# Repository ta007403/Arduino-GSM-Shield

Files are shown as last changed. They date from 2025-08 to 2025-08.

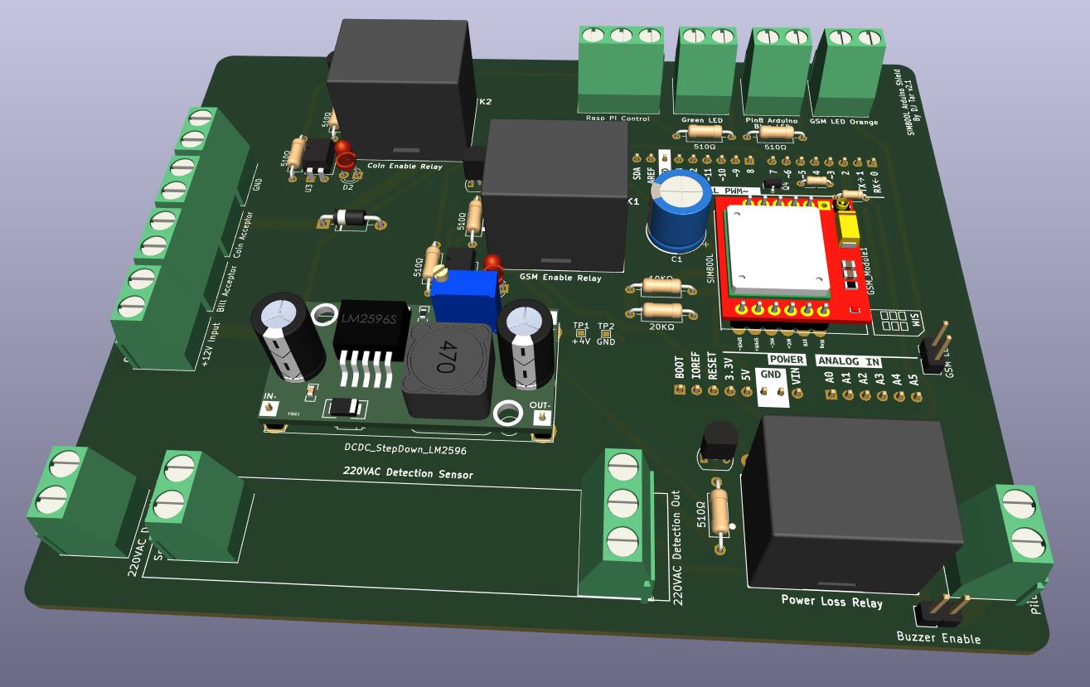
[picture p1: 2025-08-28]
plots/Smart Coin PCB Version 2.1.JPG

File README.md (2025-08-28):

Smart Coin Machine PCB (v2.1)

Smart Coin PCB Version 2 1

This project is a custom PCB for smart coin and bill acceptor machines, designed to simplify wiring, assembly, and integration with GSM modules, Arduino, and Raspberry Pi.

✨ Features

Plug & Play Wiring

Just connect +12V DC input via screw terminals.

Direct connections for coin acceptor, bill acceptor, buzzer, and status LEDs.

GSM Module Support

Compatible with SIM800L and SIM800C.

On-board relay to enable/disable GSM module.

Reset GSM via dedicated relay (Arduino Pin 7).

Built-in DC-DC step-down regulator (LM2596S) provides stable +4V supply for GSM.

Relays & Control

Coin Enable Relay → controlled by Raspberry Pi (Pin 17).

GSM Enable Relay → power cycle or disable GSM when needed.

Power Loss Relay → detect and respond to AC mains failures.

Indicators & Status LEDs

Arduino Pin 8 → Blue LED status output.

Raspberry Pi Pin 27 → Green LED status output.

GSM status LED indicators (Orange).

220VAC Detection

Input and output connectors for 220VAC detection sensor.

Useful for monitoring AC mains availability.

----------------------------------------------------------------------------------------

📐 Hardware Overview

Main components visible on the PCB:

LM2596S DC-DC Buck Converter (12V → 4V for GSM).

3 Relays:

Coin Enable Relay

GSM Enable/Reset Relay

Power Loss Relay

Connectors:

12V DC input

Coin acceptor

Bill acceptor

Buzzer

LEDs (Arduino, Raspberry Pi, GSM)

220VAC detection input/output

GSM Module Slot (SIM800L/SIM800C footprint).

(See PCB layout in uno-r4-shield-template__Assembly.pdf
 for detailed pinouts)
.

----------------------------------------------------------------------------------------

🔌 Pin Mapping
Function	Controller	Pin
Coin Enable	Raspberry Pi	GPIO17
LED Status (Green)	Raspberry Pi	GPIO27
LED Status (Blue)	Arduino	Pin 8
GSM Reset	Arduino	Pin 7
⚡ Power

Input: +12V DC

Internal Regulator: LM2596S → +4V for GSM

Relays and acceptors powered directly from +12V line.

----------------------------------------------------------------------------------------

🚀 Use Case

This PCB is ideal for:

Smart vending or refill machines.

Coin/bill based Bitcoin Lightning machines.

GSM-enabled kiosks requiring reliable reset and status handling.

----------------------------------------------------------------------------------------

📂 Repository Contents

Smart Coin PCB Version 2.1.JPG → Rendered 3D PCB view.

uno-r4-shield-template__Assembly.pdf → PCB layout & assembly reference.

README.md → This documentation.

----------------------------------------------------------------------------------------

🛠️ Assembly Notes

Connect +12V DC power input.

Wire coin and bill acceptors into screw terminals.

Install GSM module (SIM800L or SIM800C).

Connect buzzer and LED indicators.

Connect Raspberry Pi/Arduino control lines as per pin mapping.

----------------------------------------------------------------------------------------

📜 License

This project is free to use as hobby project or commercial

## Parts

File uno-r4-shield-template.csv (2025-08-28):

Id | Designator | Footprint | Quantity | Designation | Supplier and ref
1 | Q2,Q1,Q3 | TO-92_Inline | 3 | BC337
2 | D6,D4,D7,D3 | D_DO-41_SOD81_P10.16mm_Horizontal | 4 | 1N4007
3 | K3,K1,K2 | G5LE-1 | 3 | G5LE-1-DC5
4 | J15 | TerminalBlock_Phoenix_MKDS-1,5-2-5.08_1x02_P5.08mm_Horizontal | 1 | Pilot Lamp Buzzer
5 | R9,R7,R5,R4,R12,R6,R11 | R_Axial_DIN0207_L6.3mm_D2.5mm_P10.16mm_Horizontal | 7 | 510Ω
6 | J19 | PinHeader_1x02_P2.54mm_Vertical | 1 | Buzzer Enable
7 | J18 | PinHeader_1x02_P2.54mm_Vertical | 1 | GSM LED
8 | R8,R3 | R_Axial_DIN0204_L3.6mm_D1.6mm_P5.08mm_Horizontal | 2 | 10k, +-5%
9 | Q4 | SOT-23 | 1 | BSS138
10 | J9 | TerminalBlock_Phoenix_MKDS-1,5-2-5.08_1x02_P5.08mm_Horizontal | 1 | Coin Acceptor
11 | S1 | 2MS1T1B3M2QES | 1 | +4V Enable
12 | R2 | R_Axial_DIN0207_L6.3mm_D2.5mm_P10.16mm_Horizontal | 1 | 20KΩ
13 | J6 | TerminalBlock_Phoenix_MKDS-1,5-2-5.08_1x02_P5.08mm_Horizontal | 1 | Pin8 Arduino LED Blue
14 | C1 | CP_Radial_D10.0mm_P5.00mm | 1 | 1500uF 16V
15 | U3,U2 | DIP-4_W7.62mm | 2 | EL817
16 | R1 | R_Axial_DIN0207_L6.3mm_D2.5mm_P10.16mm_Horizontal | 1 | 10KΩ
17 | J20 | TerminalBlock_Phoenix_MKDS-1,5-3-5.08_1x03_P5.08mm_Horizontal | 1 | Rasp Pi Control
18 | J12 | TerminalBlock_Phoenix_MKDS-1,5-2-5.08_1x02_P5.08mm_Horizontal | 1 | Solder Pads 2
19 | J7 | TerminalBlock_Phoenix_MKDS-1,5-2-5.08_1x02_P5.08mm_Horizontal | 1 | +12V Input
20 | J16 | TerminalBlock_Phoenix_MKDS-1,5-2-5.08_1x02_P5.08mm_Horizontal | 1 | 220VAC Detection In
21 | J3 | TerminalBlock_Phoenix_MKDS-1,5-2-5.08_1x02_P5.08mm_Horizontal | 1 | GSM LED Orange
22 | J14 | TerminalBlock_Phoenix_MKDS-1,5-2-5.08_1x02_P5.08mm_Horizontal | 1 | Pin17 Rasp Pi LED Green
23 | TP2 | TestPoint_Pad_1.0x1.0mm | 1 | GND
24 | D2,D1 | LED_D3.0mm | 2 | LED
25 | J8 | TerminalBlock_Phoenix_MKDS-1,5-2-5.08_1x02_P5.08mm_Horizontal | 1 | Bill Acceptor
26 | GSM_Module1 | SIM800L | 1 | SIM800L
27 | U1 | YAAJ_DCDC_StepDown_LM2596 | 1 | DCDC_StepDown_LM2596
28 | TP1 | TestPoint_Pad_1.0x1.0mm | 1 | +4V
29 | J13 | TerminalBlock_Phoenix_MKDS-1,5-2-5.08_1x02_P5.08mm_Horizontal | 1 | GND
30 | J17 | TerminalBlock_Phoenix_MKDS-1,5-3-5.08_1x03_P5.08mm_Horizontal | 1 | 220VAC Detection Out
31 | J1 | PinHeader_1x08_P2.54mm_Vertical | 1 | POWER1
32 | J4 | PinHeader_1x10_P2.54mm_Vertical | 1 | DIGITAL2
33 | J2 | PinHeader_1x06_P2.54mm_Vertical | 1 | ANALOG
34 | J5 | PinHeader_1x08_P2.54mm_Vertical | 1 | DIGITAL1

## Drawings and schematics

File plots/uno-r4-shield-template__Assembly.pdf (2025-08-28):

D4 Coin Acceptor | þÿ510©
þÿ510© GND | 220VAC Detection Out K2 1 | 2 | 3 | 4 | 5 | 6 1 | 2 | 3 | 4 | 5 | 6 ABCD | ABCD Date: KiCad E.D.A. kicad 7.0.7 Size: A4 | Rev:

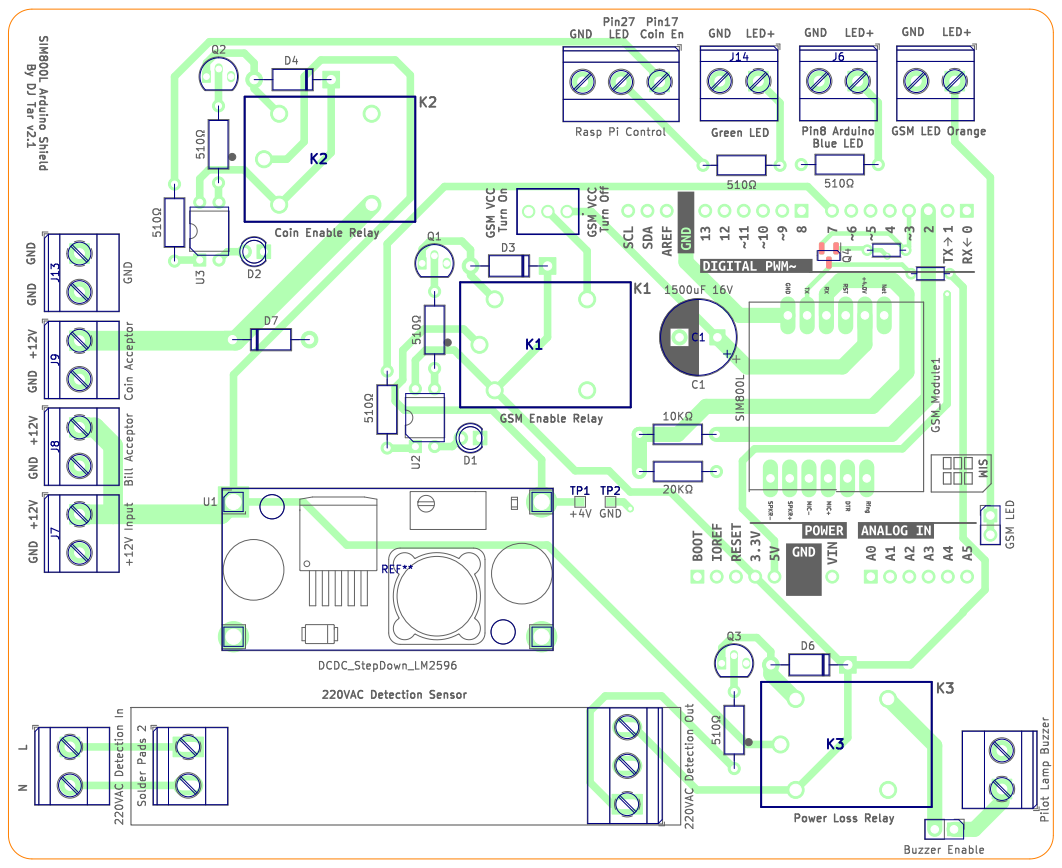
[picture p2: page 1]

Id: 1/1 Title: File: uno-r4-shield-template.kicad_pcb Sheet:K3 J9

1 | 2 | 3 | 4 | 5 | 6

A

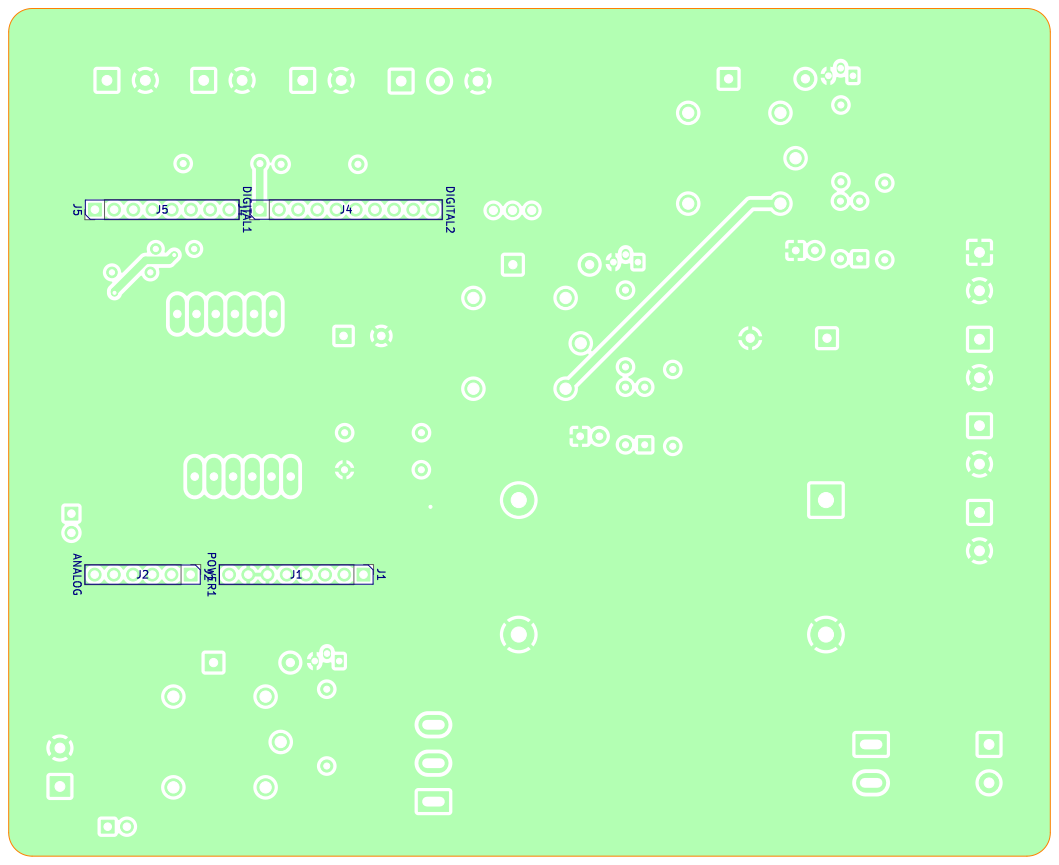
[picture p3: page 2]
D Date: KiCad; kicad; 7.0.7 Size: A4; Rev:; Id: 1/1 Title: File: uno-r4-shield-template.kicad_pcb Sheet: J1 POWER¹; DIGITAL2 J4 J2 ANALOG; DIGITAL1 J5

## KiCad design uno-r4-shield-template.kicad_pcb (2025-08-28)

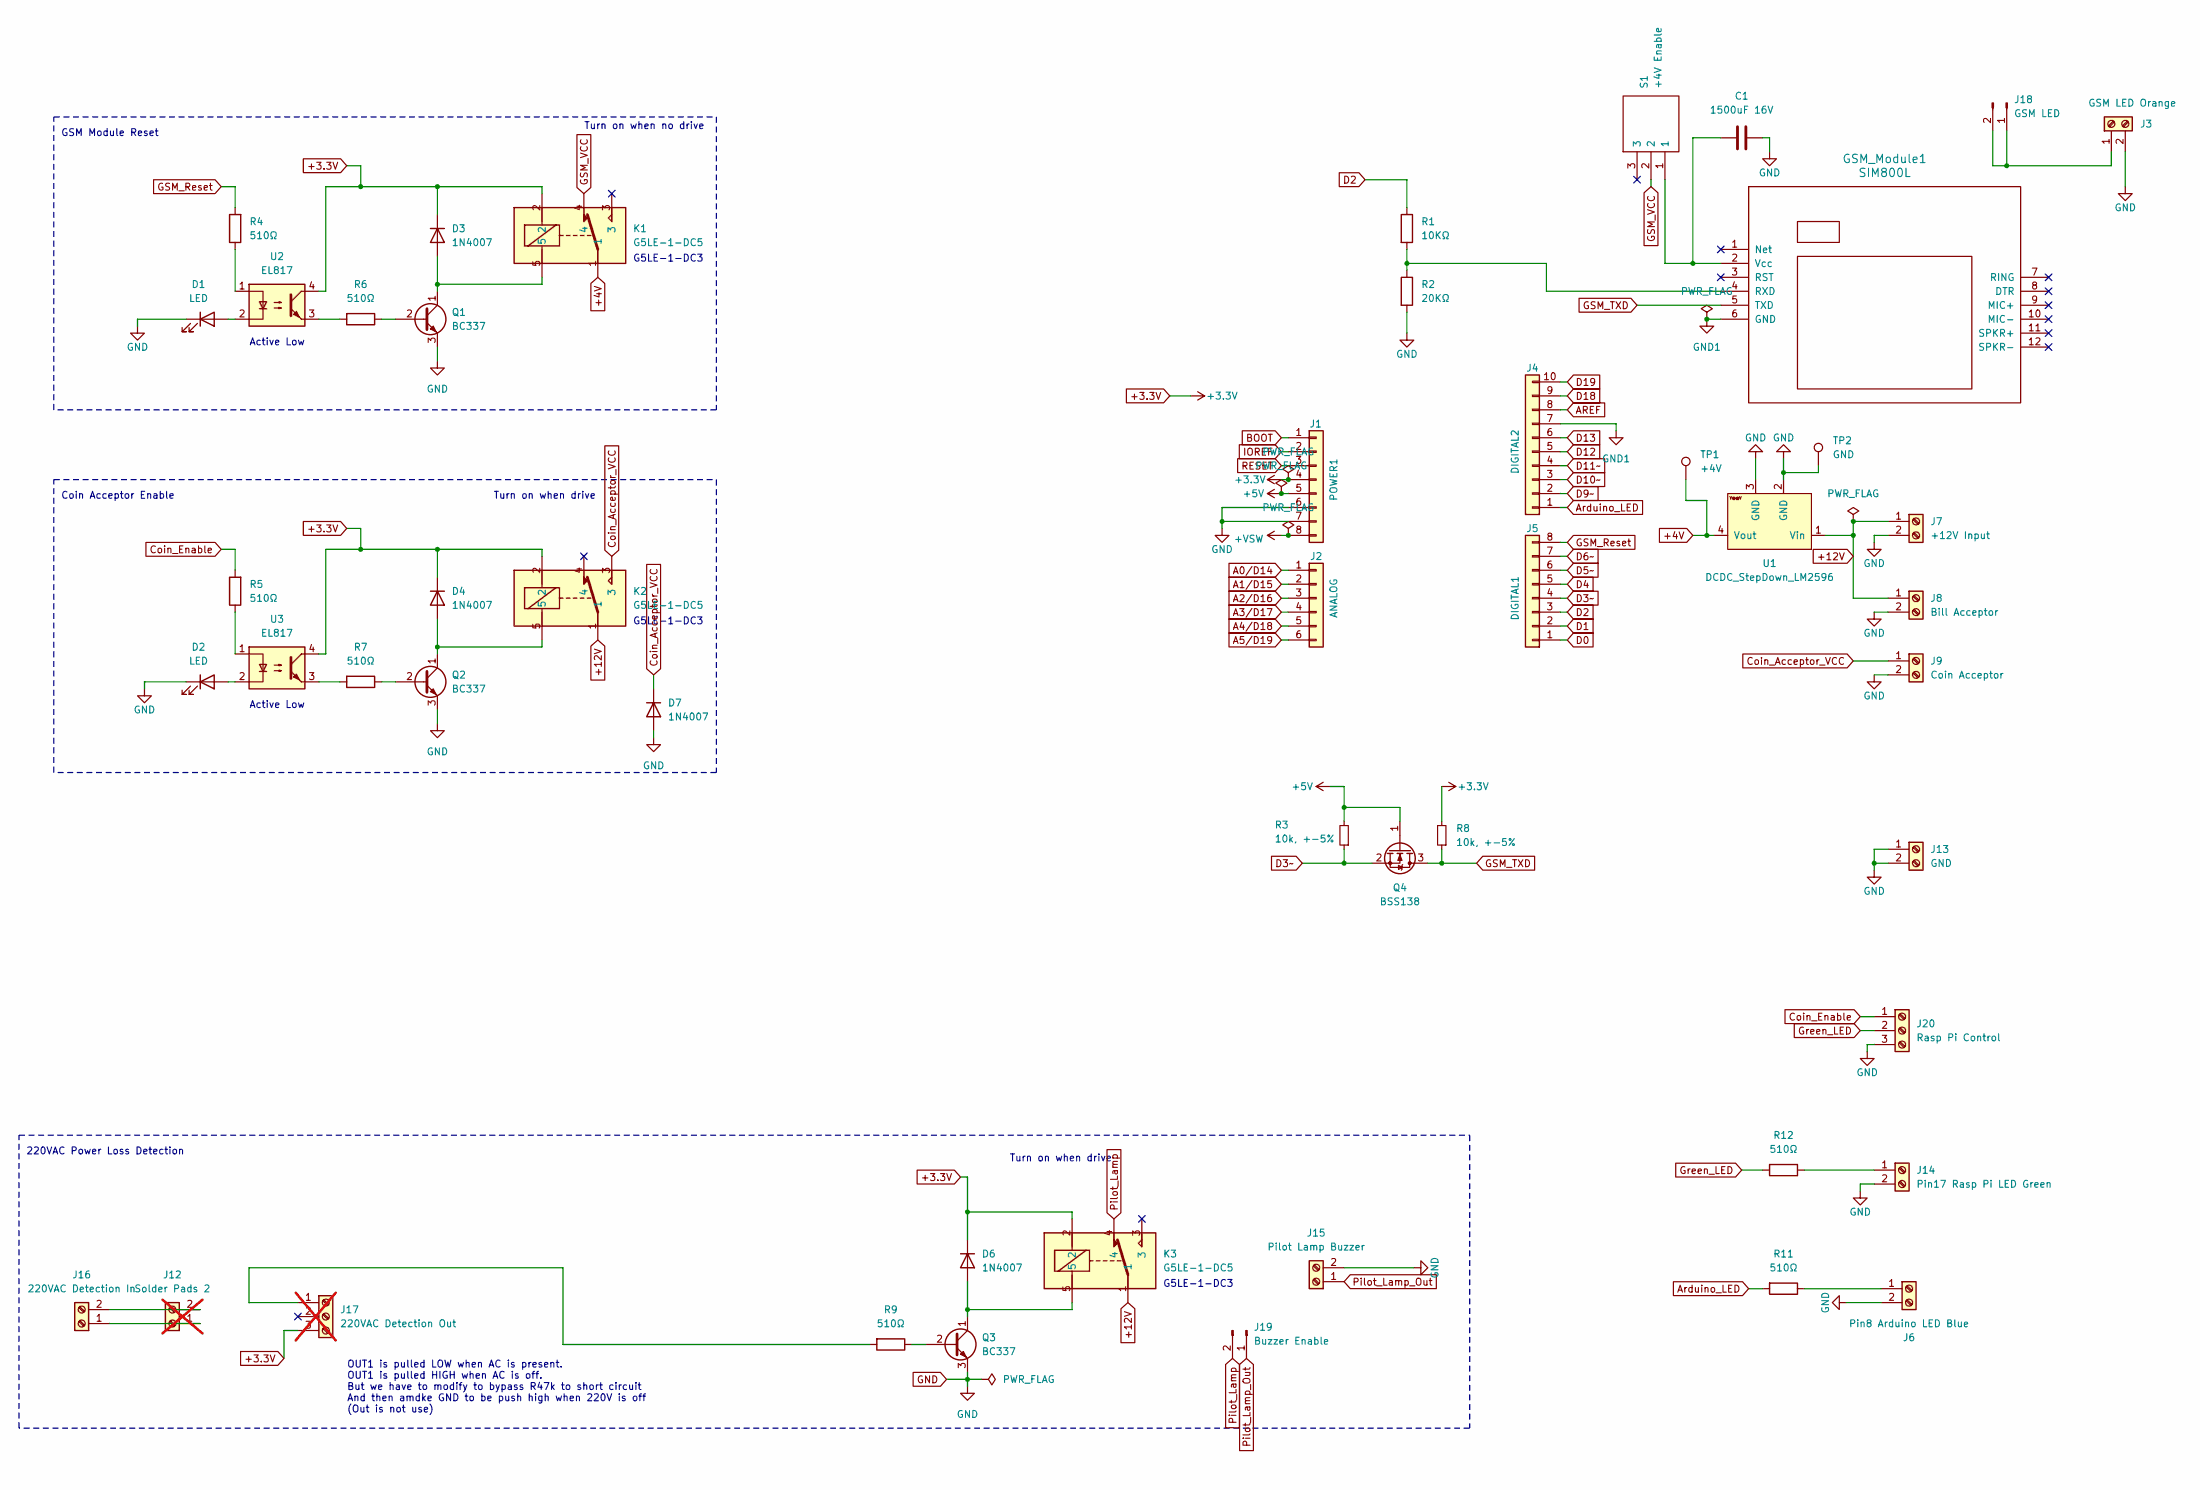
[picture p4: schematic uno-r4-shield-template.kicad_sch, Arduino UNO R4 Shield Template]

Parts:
C1: 1500uF 16V; CP_Radial_D10.0mm_P5.00mm
D1, D2: LED; LED_D3.0mm
D3, D4, D6, D7: 1N4007; D_DO-41_SOD81_P10.16mm_Horizontal
GSM_Module1: SIM800L
J1: POWER1; PinHeader_1x08_P2.54mm_Vertical
J2: ANALOG; PinHeader_1x06_P2.54mm_Vertical
J3: GSM LED Orange; TerminalBlock_Phoenix_MKDS-1,5-2-5.08_1x02_P5.08mm_Horizont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
J4: DIGITAL2; PinHeader_1x10_P2.54mm_Vertical
J5: DIGITAL1; PinHeader_1x08_P2.54mm_Vertical
J6: Pin8 Arduino LED Blue; TerminalBlock_Phoenix_MKDS-1,5-2-5.08_1x02_P5.08mm_Horizont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
J7: +12V Input; TerminalBlock_Phoenix_MKDS-1,5-2-5.08_1x02_P5.08mm_Horizont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
J8: Bill Acceptor; TerminalBlock_Phoenix_MKDS-1,5-2-5.08_1x02_P5.08mm_Horizont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
J9: Coin Acceptor; TerminalBlock_Phoenix_MKDS-1,5-2-5.08_1x02_P5.08mm_Horizont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
J12: Solder Pads 2; TerminalBlock_Phoenix_MKDS-1,5-2-5.08_1x02_P5.08mm_Horizont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; not fitted
J13: GND; TerminalBlock_Phoenix_MKDS-1,5-2-5.08_1x02_P5.08mm_Horizont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
J14: Pin17 Rasp Pi LED Green; TerminalBlock_Phoenix_MKDS-1,5-2-5.08_1x02_P5.08mm_Horizont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
J15: Pilot Lamp Buzzer; TerminalBlock_Phoenix_MKDS-1,5-2-5.08_1x02_P5.08mm_Horizont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
J16: 220VAC Detection In; TerminalBlock_Phoenix_MKDS-1,5-2-5.08_1x02_P5.08mm_Horizont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
J17: 220VAC Detection Out; TerminalBlock_Phoenix_MKDS-1,5-3-5.08_1x03_P5.08mm_Horizont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; not fitted
J18: GSM LED; PinHeader_1x02_P2.54mm_Vertical
J19: Buzzer Enable; PinHeader_1x02_P2.54mm_Vertical
J20: Rasp Pi Control; TerminalBlock_Phoenix_MKDS-1,5-3-5.08_1x03_P5.08mm_Horizont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
K1, K2, K3: G5LE-1-DC5; G5LE-1; Mouser Part Number 653-G5LE-1-DC5
Q1, Q2, Q3: BC337; TO-92_Inline
Q4: BSS138; SOT-23; Mfr. Part # BSS138
R1: 10KΩ; R_Axial_DIN0207_L6.3mm_D2.5mm_P10.16mm_Horizontal
R2: 20KΩ; R_Axial_DIN0207_L6.3mm_D2.5mm_P10.16mm_Horizontal
R3, R8: 10k, +-5%; R_Axial_DIN0204_L3.6mm_D1.6mm_P5.08mm_Horizontal; Mfr. Part # RT0402FRE0710KL; LCSC Part # C25804
R4, R5, R6, R7, R9, R11, R12: 510Ω; R_Axial_DIN0207_L6.3mm_D2.5mm_P10.16mm_Horizontal
S1: +4V Enable; 2MS1T1B3M2QES; Mouser Part Number 118-2MS1T1B3M2QES
TP1: +4V; TestPoint_Pad_1.0x1.0mm
TP2: GND; TestPoint_Pad_1.0x1.0mm
U1: DCDC_StepDown_LM2596; YAAJ_DCDC_StepDown_LM2596
U2, U3: EL817; DIP-4_W7.62mm

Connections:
+3.3V: D3.1 (K), D4.1 (K), D6.1 (K), J1.4, J17.3, K1.2, K2.2, K3.2, R8.2, U2.4, U3.4
+4V: K1.1, TP1.1, U1.4 (Vout)
+5V: J1.5, Q4.1 (G), R3.2
+12V: J7.1, J8.1, K2.1, K3.1, U1.1 (Vin)
+VSW: J1.8
A0/D14: J2.1
A1/D15: J2.2
A2/D16: J2.3
A3/D17: J2.4
A4/D18: J2.5
A5/D19: J2.6
AREF: J4.8
Arduino_LED: J4.1, R11.2
BOOT: J1.1
Coin_Acceptor_VCC: D7.1 (K), J9.1, K2.3
Coin_Enable: J20.1, R5.2
D0: J5.1
D1: J5.2
D2: J5.3, R1.1
D3~: J5.4, Q4.2 (S), R3.1
D4: J5.5
D5~: J5.6
D6~: J5.7
D9~: J4.2
D10~: J4.3
D11~: J4.4
D12: J4.5
D13: J4.6
D18: J4.9
D19: J4.10
GND: C1.2, D1.1 (K), D2.1 (K), D7.2 (A), J1.6, J1.7, J3.2, J6.2, J7.2, J8.2, J9.2, J13.1, J13.2, J14.2, J15.2, J20.3, Q1.3 (E), Q2.3 (E), Q3.3 (E), R2.2, TP2.1, U1.2 (GND), U1.3 (GND)
GND1: GSM_Module1.6 (GND), J4.7
GSM_Reset: J5.8, R4.2
GSM_TXD: GSM_Module1.5 (TXD), Q4.3 (D), R8.1
GSM_VCC: K1.4, S1.2
Green_LED: J20.2, R12.2
IOREF: J1.2
unnamed: D1.2 (A), U2.2
unnamed: D2.2 (A), U3.2
unnamed: D3.2 (A), K1.5, Q1.1 (C)
unnamed: D4.2 (A), K2.5, Q2.1 (C)
unnamed: D6.2 (A), K3.5, Q3.1 (C)
unnamed: GSM_Module1.4 (RXD), R1.2, R2.1
unnamed: C1.1, GSM_Module1.2 (Vcc), S1.1
unnamed: J6.1, R11.1
unnamed: J12.1, J16.1
unnamed: J12.2, J16.2
unnamed: J14.1, R12.1
unnamed: J17.1, R9.2
unnamed: J3.1, J18.1, J18.2
unnamed: Q1.2 (B), R6.1
unnamed: Q2.2 (B), R7.1
unnamed: Q3.2 (B), R9.1
unnamed: R4.1, U2.1
unnamed: R5.1, U3.1
unnamed: R6.2, U2.3
unnamed: R7.2, U3.3
Pilot_Lamp: J19.2, K3.4
Pilot_Lamp_Out: J15.1, J19.1
RESET: J1.3

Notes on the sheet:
G5LE-1-DC3
Active Low
Turn on when drive
Coin Acceptor Enable
GSM Module Reset
Turn on when no drive
OUT1 is pulled LOW when AC is present. OUT1 is pulled HIGH when AC is off. But we have to modify to bypass R47k to short circuit And then amdke GND to be push high when 220V is off (Out is not use)
220VAC Power Loss Detection

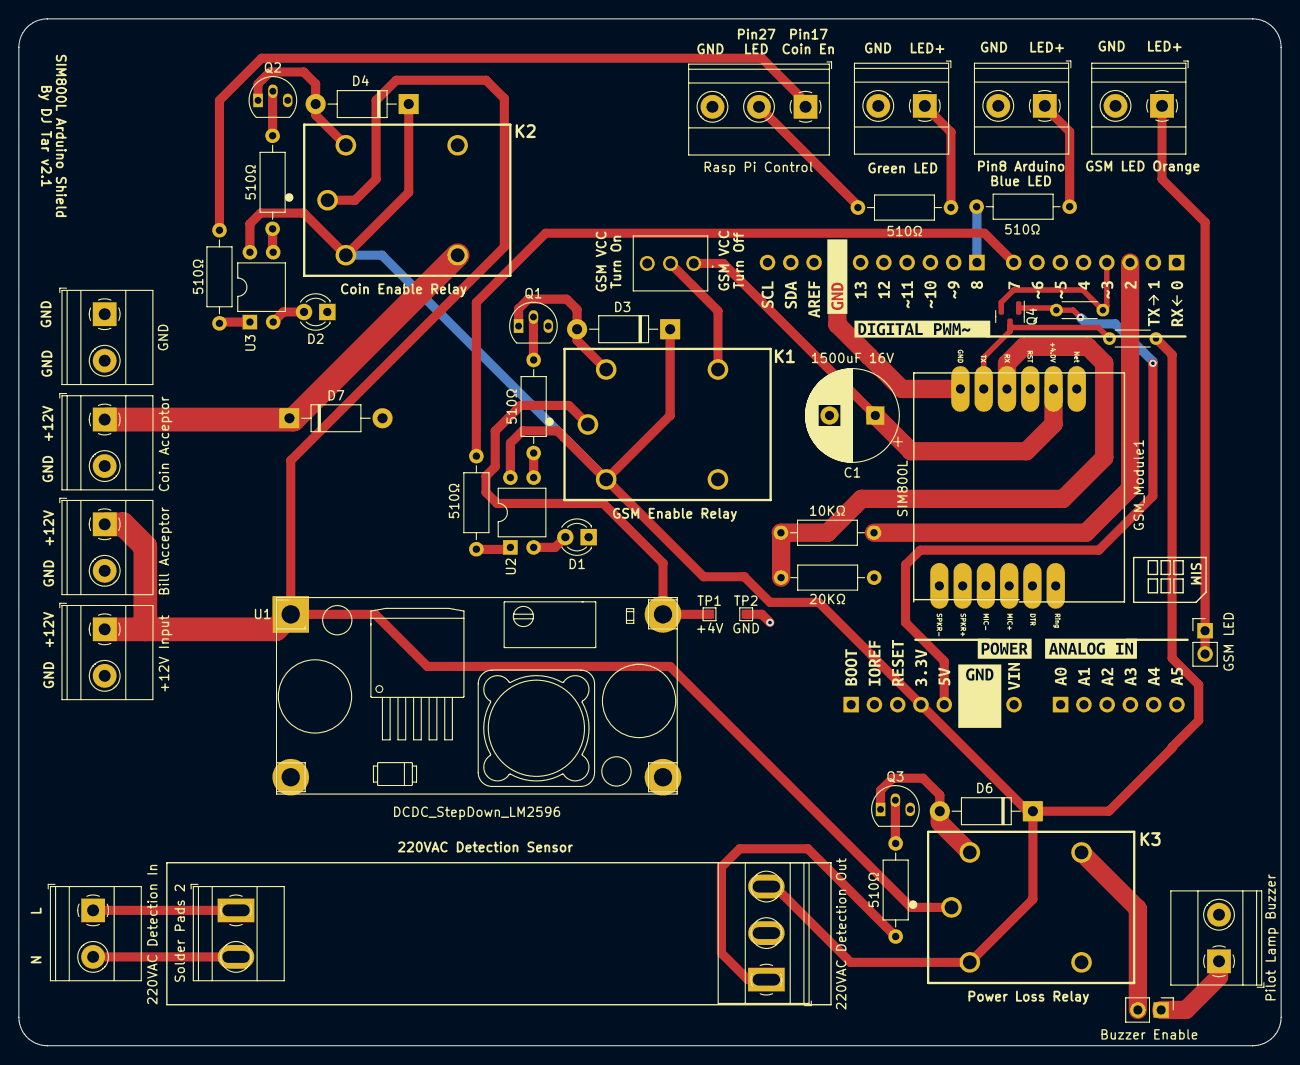
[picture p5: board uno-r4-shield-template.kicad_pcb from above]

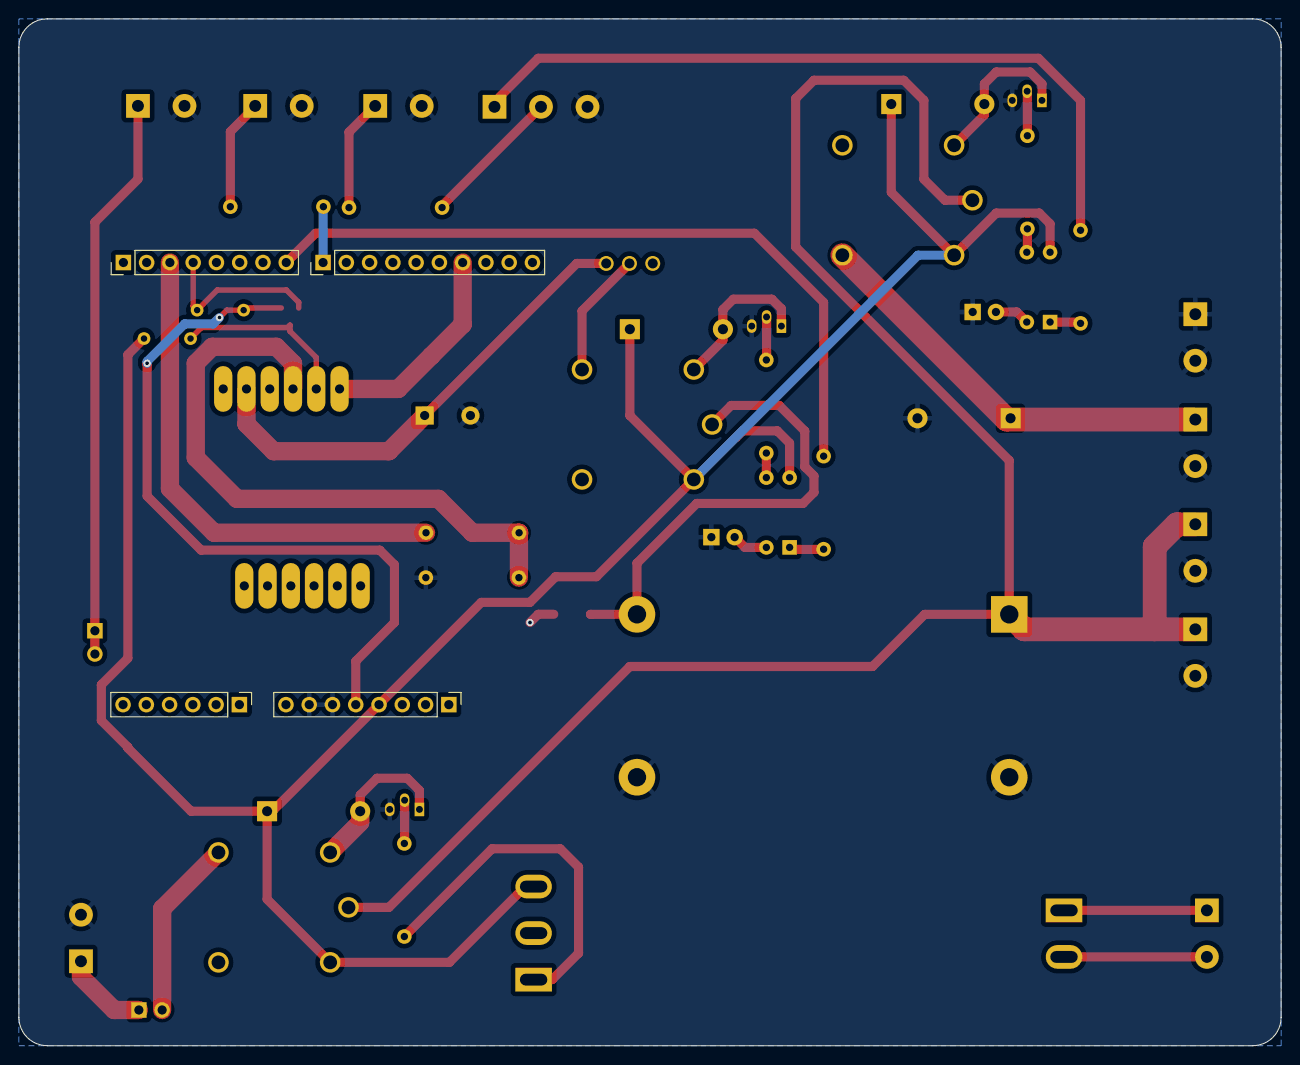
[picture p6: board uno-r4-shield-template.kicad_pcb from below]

Board: 2 copper layers, 137.8 x 112.1 mm, 86 parts (4 on the bottom side), 37 nets.

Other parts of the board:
kibuzzard-64EA1AE1: G***; kibuzzard-64EA1AE1
kibuzzard-64EA1B1D: G***; kibuzzard-64EA1B1D
kibuzzard-64EA1B42: G***; kibuzzard-64EA1B42
kibuzzard-64EA15CB: G***; kibuzzard-64EA15CB
kibuzzard-64EA16B9: G***; kibuzzard-64EA16B9
kibuzzard-64EA153F: G***; kibuzzard-64EA153F
kibuzzard-64EA162C: G***; kibuzzard-64EA162C
kibuzzard-64EA177C: G***; kibuzzard-64EA177C
kibuzzard-64EA1511: G***; kibuzzard-64EA1511
kibuzzard-64EA1739: G***; kibuzzard-64EA1739
kibuzzard-64EA1767: G***; kibuzzard-64EA1767
kibuzzard-636462BB: G***; kibuzzard-636462BB
kibuzzard-636463B1: G***; kibuzzard-636463B1
kibuzzard-636463C7: G***; kibuzzard-636463C7
kibuzzard-636463E3: G***; kibuzzard-636463E3
kibuzzard-636464C1: G***; kibuzzard-636464C1
kibuzzard-636464E7: G***; kibuzzard-636464E7
kibuzzard-636465A9: G***; kibuzzard-636465A9
kibuzzard-636466AF: G***; kibuzzard-636466AF
kibuzzard-6364607A: G***; kibuzzard-6364607A
kibuzzard-6364651D: G***; kibuzzard-6364651D
kibuzzard-6364657A: G***; kibuzzard-6364657A
kibuzzard-6364668F: G***; kibuzzard-6364668F
kibuzzard-6364669B: G***; kibuzzard-6364669B
kibuzzard-63646068: G***; kibuzzard-63646068
kibuzzard-63646358: G***; kibuzzard-63646358
kibuzzard-63646507: G***; kibuzzard-63646507
kibuzzard-63646512: G***; kibuzzard-63646512
kibuzzard-63646593: G***; kibuzzard-63646593
kibuzzard-63646605: G***; kibuzzard-63646605
kibuzzard-63646671: G***; kibuzzard-63646671
kibuzzard-63646688: G***; kibuzzard-63646688
kibuzzard-63646694: G***; kibuzzard-63646694
kibuzzard-63656678: G***; kibuzzard-63656678
kibuzzard-63659483: G***; kibuzzard-63659483
kibuzzard-63659489: G***; kibuzzard-63659489
